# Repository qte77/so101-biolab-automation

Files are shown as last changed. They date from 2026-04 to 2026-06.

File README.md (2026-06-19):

# so101-biolab-automation

> **PROTOTYPE** — This project is in early development. Hardware designs are untested, CAD dimensions are approximate, and USB protocols are being reverse-engineered. Not ready for production use. Contributions and feedback welcome.














Dual-path bio-lab automation: SO-101 arms for complex tasks + XZ gantry for dedicated pipetting. Supports commercial electronic pipettes (AELAB dPette, DLAB dPette+) and Bento Lab PCR.

See [docs/UserStory.md](docs/UserStory.md) for use cases (UC1-5) and acceptance criteria.

**Background:** this is the lab scaffold behind [Building a Trustworthy Agent Loop for a Physical Lab](https://qte77.github.io/open-self-driving-lab-agent-loop/).

## Hardware

**SO-101 path:** Two [SO-101](https://github.com/therobotstudio/so-arm100) follower arms + one leader arm via [LeRobot](https://huggingface.co/docs/lerobot/index). ~$350–$650.

**XZ gantry path:** Dedicated 2-axis pipetting arm (MGN12 rails + NEMA17 steppers). ~$60–$80.

See [docs/hardware/BOM.md](docs/hardware/BOM.md) for full shopping list with links.

## Quick Start

```bash
# Setup (all deps + tools)
make setup_all

# Generate 3D-printed parts (build123d preferred, OpenSCAD fallback)
# STL + STEP + SVG written to hardware/. STEP is the FreeCAD round-trip
# escape hatch when parametric editing is awkward — see docs/hardware/cad-tooling.md.
make render_parts

# Optional: validate printability (CuraEngine / PrusaSlicer)
make setup_slicer
make check_prints

# --- Hardware bringup (one-time) ---

# Install LeRobot deps (PyPI wheels first; falls back to build-from-source if needed)
make setup_hardware

# Identify USB serial ports for each board (unplug one at a time when prompted)
make find_port

# Fix /dev/ttyACM* permissions (one-time; replug boards after)
make install_udev

# Scan servos + patch lerobot for mixed STS3215 firmware
make bringup PORT=/dev/ttyACM1

# Calibrate arms (move each through its full range when prompted)
make calibrate_arms                       # full 3-arm setup (leader + arm_a + arm_b)
# for 2-arm setups (leader + one follower) run only what is connected:
# make calibrate_arm_a calibrate_leader

# Teleoperate (teacher-student)
make start_teleop                         # uses cameras by default
# or headless (no cameras):
# make start_teleop CAMERAS="{}"

# Record pipetting episodes
make record_episodes TASK="pipette row A"

# Train policy
make train_policy

# Run demo
make run_demo
```

## Live Visualization

`make start_teleop` and `make record_episodes` open [Rerun.io](https://rerun.io)
automatically (via `--display_data=true`).

<details>
<summary>Rerun.io live teleop view — click to expand</summary>

Rerun.io live teleop view

- **Top panel** — time-series of commanded `action.*.pos` vs observed `observation.*.pos` for each joint (shoulder_pan, shoulder_lift, elbow_flex, wrist_flex, wrist_roll, gripper)
- **Bottom panel** — observation streams aligned to the action timeline
- **Right panel** — recording metadata (ID, app, timestamps)
- **Left panel** — recording list + blueprint

Useful for verifying leader→follower tracking lag, joint-range coverage during recording, and gripper actuation timing.

</details>

For a separate live 3D arm + camera view (Foxglove), run `make start_foxglove`.

## Architecture

Workspace Layout

See [docs/architecture.md](docs/architecture.md) for full system design, module responsibilities, and data flows.

## Project Structure

- `src/so101/` — core library + CLI entry points (arms, pipette, workflow, safety, ELN)
- `src/dashboard/` — FastAPI remote oversight dashboard
- `src/hardware/` — CAD pipeline (build123d, slicer, renderer)
- `hardware/` — generated STLs, SVGs, 3D scan data
- `configs/` — YAML runtime config (ports, positions, backends)
- `docs/` — design, user stories, demo scenarios, BOM, research, hardware bringup
- `tests/` — unit, integration, property-based tests (80% coverage gate)

See [docs/architecture.md](docs/architecture.md) for module responsibilities and data flows.

## CLI Entry Points

```bash
uv run so101-demo              # run demo pipetting workflows
uv run so101-coord             # send coordinate commands to an arm
uv run so101-scan-servos       # scan serial port for STS3215 servos
uv run so101-patch-lerobot     # patch lerobot for mixed firmware (prototyping)
```

## Documentation

- [Architecture](docs/architecture.md) — system design, module responsibilities, data flows
- [User Stories](docs/UserStory.md) — use case (UC1-5) acceptance criteria
- [Demo Scenarios](docs/demo-scenarios.md) — how to run and verify each use case
- [Hardware BOM](docs/hardware/BOM.md) — shopping list with links ($350-$3000+)
- [Hardware Bringup](docs/hardware/bringup.md) — SO-101 calibration, teleop, firmware patches
- [Research](docs/research.md) — prior art, papers, community designs, insights
- [Roadmap](docs/roadmap.md) — closed-loop printing, tool genesis, VLM/embodied AI vision

## Key Dependencies

- [LeRobot](https://github.com/huggingface/lerobot) — Teleoperation + imitation learning
- [PyLabRobot](https://github.com/PyLabRobot/pylabrobot) — Liquid handling abstractions
- [digital-pipette-v2](https://github.com/ac-rad/digital-pipette-v2) — DIY pipette (alternative backend)
- [build123d](https://github.com/gumyr/build123d) — Primary CAD for 3D-printed parts
- [OpenSCAD](https://openscad.org/) — Fallback CAD for 3D-printed parts
- [CuraEngine](https://github.com/Ultimaker/CuraEngine) — Printability validation (headless, preferred)
- [PrusaSlicer](https://github.com/prusa3d/PrusaSlicer) — Printability validation (fallback)
- FastAPI + WebRTC — Remote dashboard
- OpenCV — Camera pipeline

## Development

For dev setup, testing, and contribution workflow, see [CONTRIBUTING.md](CONTRIBUTING.md) and [AGENTS.md](AGENTS.md).
Run `make help` to list available targets; `make validate` is the canonical quality gate.

## Roadmap

Toward general-purpose voice/agent-to-print. See [docs/roadmap.md](docs/roadmap.md) for full vision (human loop, agent loop, autonomous tool genesis, VLM/embodied AI phases).

## License

Apache-2.0

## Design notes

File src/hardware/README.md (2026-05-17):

---
title: Hardware Parts
purpose: 3D-printable parts index with print settings, assembly, scan references, and source scripts
created: 2026-03-27
updated: 2026-04-11
---

# Hardware Parts

Generated from `parts.json` manifest via `render.py` (build123d preferred, OpenSCAD fallback).

```bash
make setup_cad            # Install build123d (preferred)
make setup_scad           # Install OpenSCAD (fallback)
make render_parts         # Generate STL + SVG from parts.json
make setup_slicer         # Install slicer (optional)
make check_prints         # Check printability
make render_all           # Generate + validate
```

**How it works:** `hardware/parts.json` defines all parts (names, filenames, scripts, build functions). `hardware/render.py` reads the manifest and dispatches to build123d (imports `build_func`, exports STL+SVG) or OpenSCAD (CLI calls with `scad_args`). Adding a part means editing `parts.json` and writing the script.

**Why build123d + slicer?** build123d generates parametric STLs with isometric wireframe SVGs. A slicer (CuraEngine / PrusaSlicer) validates FDM printability (overhangs, unsupported regions, gravity failures) as fast CLI feedback.

**Fallback for hand-edits:** STEP files are exported alongside STL into `../../hardware/step/` so parts can be opened in FreeCAD for WYSIWYG edits (face drag, manual fillet) when parametric Python is awkward. The hand-edited STEP becomes the source of truth for that part — no re-import to build123d. See [../../docs/hardware/cad-tooling.md](../../docs/hardware/cad-tooling.md#hand-edit-round-trip-fallback) for the round-trip and FreeCAD install pointer.

**Status:** EXPERIMENTAL = draft dimensions, untested on hardware.

Generated STL/SVG outputs and reference scans live under the top-level `../../hardware/` directory; only code lives here. See [../../docs/architecture.md](../../docs/architecture.md#hardware-asset-layout) for the authoritative layout description.

## System Overview

Workspace Layout

## Print Settings

| Setting | Default | Exception |
|---|---|---|
| Material | PLA+ | `gripper_tips_tpu.stl` → TPU 95A |
| Nozzle | 0.4mm | — |
| Layer height | 0.2mm | prototype profile → 0.3mm |
| Infill | 15% | functional parts (dpette mounts, tool changer) → 25% |
| Supports | >45° | disabled by default |

Slicer profiles (`slicer/profiles/*.ini`):

- **Generic:** `pla_plus_02mm.ini`, `tpu_95a_02mm.ini` — printer-agnostic
- **Prusa MK4:** `prusa_mk4_pla_02mm.ini` (production), `prusa_mk4_pla_prototype.ini` (fast fit-check), `prusa_mk4_pla_prototype_supports.ini` (with auto-supports), `prusa_mk4_tpu_02mm.ini` (gripper tips on MK4)

Upload to an Original Prusa MK4 via PrusaLink — see [../../docs/hardware/prusa-mk4-ops.md](../../docs/hardware/prusa-mk4-ops.md) for the endpoint reference + curl examples.

## Parts & Assembly

### Tool Changer System

Passive tool changing based on [Berkeley design](https://goldberg.berkeley.edu/pubs/CASE2018-ron-tool-changer-submitted.pdf) (truncated cone + dowel pins + magnets).

| Part | Preview |
|---|---|
| Robot-side cone (female) | tool_cone_robot |
| Tool-side cone — pipette | tool_cone_pipette |
| Tool-side cone — gripper | tool_cone_gripper |
| 3-station dock | tool_dock |

**Assembly order:**

1. **`tool_cone_robot.stl`** — Mount on SO-101 wrist (motor 5 horn, 4× M3 screws). Stays on arm permanently.
2. **`tool_cone_pipette/gripper.stl`** — Attach one to each tool. Glue or screw to tool base.
3. **`tool_dock_3station.stl`** — Fix to workspace. Insert 5mm neodymium magnets in each slot bottom.

**Tool change sequence:** Approach dock → insert tool → retract → move to new slot → push onto cone → retract with new tool.

### Pipette Setup

| Part | Preview |
|---|---|
| Pipette mount | pipette_mount |

1. **`pipette_mount_so101.stl`** — Clamp around dPette barrel. Tighten with 2× M3 screws.
2. Attach `tool_cone_pipette.stl` to mount base (4× M3 or glue).
3. **`tip_rack_holder.stl`** — Place on workspace, insert tip rack. Arm picks tips by pressing pipette into rack.

| Part | Preview |
|---|---|
| Tip rack holder | tip_rack |

### Plate Handling

| Part | Preview |
|---|---|
| 96-well plate holder | plate_holder |

1. **`96well_plate_holder.stl`** — Place at known position. 4 alignment pins locate the plate.

### Gripper Enhancement

| Part | Preview |
|---|---|
| Gripper tips (TPU) | gripper_tips |

1. **`gripper_tips_tpu.stl`** — Press-fit or glue onto SO-101 gripper fingers. Print in TPU 95A.

### dPette+ 8-Channel Mount (replaces SO-101 gripper jaws)

Derived from a 1:1 mm Revopoint 3D scan of the DLAB dPette+ handle (see [Scan Reference Data](#scan-reference-data)). Replaces the stock gripper jaws with a dedicated dPette+ mount:

| Part | Preview |
|---|---|
| Pipette clamp (replaces bottom jaw) | dpette_multi_handle |
| Ejector lever (replaces top jaw) | dpette_ejector_lever |
| Tip ejector station | dpette_tip_release |

**Assembly:**

1. **`dpette_multi_handle.stl`** — Bolts to M5 horn (4× M3 on 20mm BC). Ø32mm split bore clamps the round dPette+ handle; 2× M3 pinch bolts tension the clamp.
2. **`dpette_ejector_lever.stl`** — Bolts to M6 horn (25T spline + 4× M2 on 16mm BC). When M6 rotates (gripper-close motion), the 20mm arm sweeps and pushes down on the ejector hook (~175N from 35 kg-cm stall torque).
3. **`dpette_tip_release.stl`** — L-bracket tip ejector station at a fixed waste position. Robot moves pipette laterally into the horizontal finger to trigger tip ejection; wide waste slot fits both single- and 8-channel tip falls.

### dPette Single-Channel Mount (alternative)

| Part | Preview |
|---|---|
| U-bracket handle | dpette_handle |
| Cam arm | dpette_cam_arm |

1. **`dpette_handle.stl`** — U-bracket (single-sided C-frame): top bar bolts to M5 horn, vertical side holds M6 motor, bottom bar clamps the dPette 7016 single-channel barrel (Ø20mm bore + pinch bolt split).
2. **`dpette_cam_arm.stl`** — Straight radial arm on M6 horn. Sweeps into the ejector hook when M6 rotates.

## Scan Reference Data

Parametric CAD scripts in `cad/dpette/` may be informed by 3D scan data (structured-light scanners like Revopoint) when a physical reference is available. Scans live at the top-level `../../hardware/scans/` directory, **separate** from generated STL/SVG outputs.

Current scans:

| File | Size | Derived parts |
|---|---|---|
| [`../../hardware/scans/dpette/0410_02_mesh.ply`](../../hardware/scans/dpette/0410_02_mesh.ply) | ~2.3 MB | `dpette_multi_handle`, `dpette_ejector_lever` |
| [`../../hardware/scans/dpette/0410_02_mesh.stl`](../../hardware/scans/dpette/0410_02_mesh.stl) | ~4.6 MB | (same; mesh conversion of the PLY above) |

Parts derived from a scan carry an optional `scan_source` field in `parts.json` pointing at the scan file — queryable for tool-genesis workflows and design audits. See [../../hardware/scans/dpette/README.md](../../hardware/scans/dpette/README.md) for provenance and scale.

## Parts Catalog

The machine-readable manifest of all parts (name, STL/SVG outputs, CAD source, build function, status, backend, scan source) is [`parts.json`](parts.json). It is the single source of truth — `render.py` reads it to generate outputs, tests validate it, and this README links to it rather than duplicating it.

Query examples:

```bash
# List all active parts
jq '.[] | select(.status == "active") | .name' src/hardware/parts.json

# Find scan-derived parts
jq '.[] | select(.scan_source) | {name, scan_source}' src/hardware/parts.json
```

## Structural Review Checklist

Before printing, verify each STL:

- [ ] **Mesh integrity** — run `python hardware/slicer/validate.py --all --structural` (checks triangle count, file size)
- [ ] **Connected geometry** — no floating/disconnected features (open in slicer preview, rotate all angles)
- [ ] **Minimum wall thickness** — 0.8mm for 0.4mm nozzle (2 perimeters minimum)
- [ ] **Overhangs** — no unsupported angles > 45° (or add supports)
- [ ] **Bed adhesion** — flat bottom face exists (no point/edge contact)
- [ ] **Fit check** — mating dimensions match hardware (servo horns, magnets, pipette barrel)

## Hardware Needed (Non-Printed)

- 5mm × 3mm neodymium magnets (3 for dock, 4 for cone pairs)
- M3 × 8mm screws (4 for wrist mount, 2 per pipette clamp)
- Glue (CA or epoxy) for cone-to-tool bonding

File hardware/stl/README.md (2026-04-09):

---
title: STL Files Index
purpose: Index of 3D-printable parts with status, print settings, assembly, and source scripts
created: 2026-03-27
updated: 2026-03-30
---

# STL Files

Generated from `../parts.json` manifest via `../render.py` (CadQuery preferred, OpenSCAD fallback).

```bash
make setup_cad            # Install CadQuery (preferred)
make setup_scad           # Install OpenSCAD (fallback)
make render_parts         # Generate STL + SVG from parts.json
make setup_slicer         # Install PrusaSlicer (optional)
make check_prints         # Check printability
make render_all           # Generate + validate
```

**How it works:** `hardware/parts.json` defines all parts (names, filenames, scripts, build functions). `hardware/render.py` reads the manifest and dispatches to CadQuery (imports `build_func`, exports STL+SVG) or OpenSCAD (CLI calls with `scad_args`). Adding a part means editing `parts.json` and writing the script.

**Why CadQuery + slicer?** CadQuery generates parametric STLs with isometric wireframe SVGs. PrusaSlicer validates FDM printability (overhangs, unsupported regions, gravity failures) as fast CLI feedback.

**Status:** EXPERIMENTAL = draft dimensions, untested on hardware.

## System Overview

Workspace Layout

## Print Settings

| Setting | Default | Exception |
|---|---|---|
| Material | PLA+ | `gripper_tips_tpu.stl` → TPU 95A |
| Nozzle | 0.4mm | — |
| Layer height | 0.2mm | — |
| Infill | 15% | — |
| Supports | >45° | — |

## Parts & Assembly

### Tool Changer System

Passive tool changing based on [Berkeley design](https://goldberg.berkeley.edu/pubs/CASE2018-ron-tool-changer-submitted.pdf) (truncated cone + dowel pins + magnets).

| Part | Preview |
|---|---|
| Robot-side cone (female) | tool_cone_robot |
| Tool-side cone — pipette | tool_cone_pipette |
| Tool-side cone — gripper | tool_cone_gripper |
| 3-station dock | tool_dock |

**Assembly order:**

1. **`tool_cone_robot.stl`** — Mount on SO-101 wrist (motor 5 horn, 4× M3 screws). Stays on arm permanently.
2. **`tool_cone_pipette/gripper.stl`** — Attach one to each tool. Glue or screw to tool base.
3. **`tool_dock_3station.stl`** — Fix to workspace. Insert 5mm neodymium magnets in each slot bottom.

**Tool change sequence:** Approach dock → insert tool → retract → move to new slot → push onto cone → retract with new tool.

### Pipette Setup

| Part | Preview |
|---|---|
| Pipette mount | pipette_mount |

1. **`pipette_mount_so101.stl`** — Clamp around [digital-pipette-v2](https://github.com/ac-rad/digital-pipette-v2) barrel. Tighten with 2× M3 screws.
2. Attach `tool_cone_pipette.stl` to mount base (4× M3 or glue).
3. **`tip_rack_holder.stl`** — Place on workspace, insert tip rack. Arm picks tips by pressing pipette into rack.

| Part | Preview |
|---|---|
| Tip rack holder | tip_rack |

### Plate Handling

| Part | Preview |
|---|---|
| 96-well plate holder | plate_holder |

1. **`96well_plate_holder.stl`** — Place at known position. 4 alignment pins locate the plate.

### Gripper Enhancement

| Part | Preview |
|---|---|
| Gripper tips (TPU) | gripper_tips |

1. **`gripper_tips_tpu.stl`** — Press-fit or glue onto SO-101 gripper fingers. Print in TPU 95A.

## Parts Table

| STL File | SVG | Source | Description |
|---|-----|---|---|
| `tool_cone_robot.stl` | [svg](../svg/tool_cone_robot.svg) | `tool_changer.py` | Female cone — mounts on SO-101 wrist |
| `tool_cone_pipette.stl` | [svg](../svg/tool_cone_pipette.svg) | `tool_changer.py` | Male cone — pipette tool base |
| `tool_cone_gripper.stl` | [svg](../svg/tool_cone_gripper.svg) | `tool_changer.py` | Male cone — gripper tool base |
| `tool_dock_3station.stl` | [svg](../svg/tool_dock_3station.svg) | `so101/tool_dock.py` | 3-slot parking rack with magnet pockets |
| `pipette_mount_so101.stl` | [svg](../svg/pipette_mount_so101.svg) | `so101/pipette_mount.py` | dPette barrel clamp for SO-101 wrist |
| `96well_plate_holder.stl` | [svg](../svg/96well_plate_holder.svg) | `labware/plate_holder.py` | SBS plate holder with alignment pins |
| `tip_rack_holder.stl` | [svg](../svg/tip_rack_holder.svg) | `labware/tip_rack_holder.py` | Tip rack tray |
| `gripper_tips_tpu.stl` | [svg](../svg/gripper_tips_tpu.svg) | `so101/gripper_tips.py` | Compliant fingertips (TPU 95A) |
| `dpette_single_cradle.stl` | [svg](../svg/dpette_single_cradle.svg) | `dpette/dpette_cradle.py` | Rest cradle for dPette 7016 |
| `dpette_multi_cradle.stl` | [svg](../svg/dpette_multi_cradle.svg) | `dpette/dpette_cradle.py` | Rest cradle for dPette+ 8-channel |
| `tip_ejection_bar.stl` | [svg](../svg/tip_ejection_bar.svg) | `dpette/tip_ejection_bar.py` | Tip ejection post (top-button) |

## Structural Review Checklist

Before printing, verify each STL:

- [ ] **Mesh integrity** — run `python hardware/slicer/validate.py --all --structural` (checks triangle count, file size)
- [ ] **Connected geometry** — no floating/disconnected features (open in slicer preview, rotate all angles)
- [ ] **Minimum wall thickness** — 0.8mm for 0.4mm nozzle (2 perimeters minimum)
- [ ] **Overhangs** — no unsupported angles > 45° (or add supports)
- [ ] **Bed adhesion** — flat bottom face exists (no point/edge contact)
- [ ] **Fit check** — mating dimensions match hardware (servo horns, magnets, pipette barrel)

## Hardware Needed (Non-Printed)

- 5mm × 3mm neodymium magnets (3 for dock, 4 for cone pairs)
- M3 × 8mm screws (4 for wrist mount, 2 per pipette clamp)
- Glue (CA or epoxy) for cone-to-tool bonding

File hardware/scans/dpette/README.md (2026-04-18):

# dPette+ 3D Scan Reference Data

Source mesh used to redesign the dPette+ 8-channel mount geometry
(`src/hardware/cad/dpette/dpette_multi_handle.py` + `dpette_ejector_lever.py`).

## Files

| File | Size | Format | Source |
|---|---|---|---|
| `0410_02_mesh.ply` | ~2.3 MB | Stanford PLY (binary) | Revopoint 3D scan, 2026-04-10 |
| `0410_02_mesh.stl` | ~4.6 MB | Binary STL (derived) | PLY → STL conversion |

## Scale & Coordinates

- **1:1 mm** — no scaling applied
- Origin and axes match Revopoint scanner output (no re-orientation)

## Intended use

Reference geometry for parametric rebuilds of dPette+-specific parts.
Not meant to be 3D printed directly — use the parametric build123d
scripts in `src/hardware/cad/dpette/` for printable parts.

## Provenance

Captured by Antonio Lamb (@antomicblitz) and incorporated via PR #48.
Preserved here as-is under the project's Apache-2.0 license (same as
the rest of the repo).

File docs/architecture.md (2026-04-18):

---
title: Architecture
purpose: System design, module responsibilities, data flows, stub mode, design decisions
authority: System design (AUTHORITY)
created: 2026-03-27
updated: 2026-04-10
---

# Architecture

## System Overview

```text
┌──────────────────────────────────────────────────────┐
│                  Remote Dashboard                     │
│  FastAPI + WebSocket commands + REST /api/status      │
│  src/dashboard/server.py                              │
└──────────────────┬───────────────────────────────────┘
                   │ WebSocket: e_stop, heartbeat,
                   │ target_well, run_workflow
┌──────────────────▼───────────────────────────────────┐
│               Workflow Orchestration                  │
│  src/so101/workflow.py                               │
│  Composes modules into use cases (UC1-4)              │
│  Loads PlateLayout from configs/plate_layout.yaml     │
├──────────┬──────────┬──────────┬─────────────────────┤
│  Arms    │ Pipette  │  Tool    │  Safety             │
│  Control │ Control  │  Changer │  Monitor            │
│ arms.py  │pipette.py│tool_ch.. │ safety.py           │
└────┬─────┴────┬─────┴────┬─────┴─────────────────────┘
     │          │          │
     │     ┌────▼────┐     │
     │     │ Plate   │     │
     │     │ Geometry │     │
     │     │plate.py │     │
     │     └─────────┘     │
     │                     │
┌────▼─────────────────────▼───┐
│  LeRobot / Serial / Hardware │
│  (stub mode when unavailable)│
└──────────────────────────────┘
```

## Module Responsibilities

| Module | File | Responsibility | Dependencies |
|---|---|---|---|
| **Workflow** | `src/so101/workflow.py` | Orchestrates use cases (UC1-5) by composing other modules | arms, pipette, plate, tool_changer, xz_gantry |
| **Arms** | `src/so101/arms.py` | Dual SO-101 arm control via LeRobot. Config-driven named positions, sequences, teleoperation skeleton. Stub mode when lerobot absent. | plate (for send_to_well) |
| **Pipette** | `src/so101/pipette.py` | Multi-backend pipette control (`PipetteProtocol`). Backends: `DigitalPipette` (DIY/Arduino), `ElectronicPipette` (AELAB/DLAB). Stub mode when pyserial absent. | None |
| **XZ Gantry** | `src/so101/xz_gantry.py` | Dedicated 2-axis pipetting arm (simpler than SO-101). Stub mode when serial absent. | None |
| **Bento Lab** | `src/so101/bento_lab.py` | Portable PCR thermocycler control (lid, programs, status). Stub mode when serial absent. | None |
| **Plate** | `src/so101/plate.py` | Pure SBS 96-well coordinate math. No hardware deps. | None |
| **Tool Changer** | `src/so101/tool_changer.py` | 3-tool magnetic dock: pipette, gripper, fridge hook. | arms (for send_action) |
| **Camera** | `src/so101/camera.py` | Multi-camera capture via OpenCV. Stub mode when cv2 absent. | None |
| **Safety** | `src/so101/safety.py` | Watchdog, e-stop, joint limits. Pure Python. | None |
| **Dashboard** | `src/dashboard/server.py` | FastAPI server with WebSocket commands and REST status. | All biolab modules |

## Data Flow: Pipetting a Well

```text
User/Dashboard → workflow.pipette_well()
  1. arm.execute_sequence("arm_a", ["trough_approach", "trough_lower"])  → arms.py → LeRobot
  2. pipette.aspirate(50.0)                → pipette.py → Arduino serial (stub: track fill)
  3. arm.execute_sequence("arm_a", ["well_approach", "well_lower"])      → arms.py → LeRobot
  4. pipette.dispense(50.0)                → pipette.py → Arduino serial (stub: track fill)
```

## Data Flow: Tool Change

```text
workflow.uc2_fridge_open_grab_move()
  1. changer.change_tool(FRIDGE_HOOK)      → tool_changer.py → arms.send_action (dock sequence)
  2. arm.send_action(FRIDGE_APPROACH)       → arms.py → LeRobot
  3. arm.send_action(FRIDGE_HOOK_ENGAGED)   → arms.py → LeRobot
  4. changer.change_tool(GRIPPER)           → tool_changer.py → arms.send_action (dock sequence)
  5. arm.send_action(FRIDGE_GRAB)           → arms.py → LeRobot
```

## Configuration Files

| File | Loaded By | Content |
|---|---|---|
| `configs/arms.yaml` | `DualArmConfig.from_yaml()` | Arm ports, cameras, named positions (park, home, well_approach, etc.) |
| `configs/plate_layout.yaml` | `PlateLayout.from_yaml()` | Workspace origin, Z heights, trough position |
| `configs/tool_dock.yaml` | `ToolDockConfig.from_yaml()` | Joint arrays for 3 dock stations |
| `configs/pipette.yaml` | `_create_pipette()` | Backend selection (digital/electronic) + per-backend settings |
| `configs/xz_gantry.yaml` | `XZGantryConfig.from_yaml()` | Named positions, serial port, controller type |
| `configs/bento_lab.yaml` | `BentoLabConfig` | Serial port, PCR program definitions |

## Stub Mode

Every hardware-dependent module gracefully degrades when its dependency is unavailable:

| Module | Trigger | Behavior |
|---|---|---|
| arms.py | `ImportError` on `lerobot` | `send_action` logs and returns; `get_observation` returns `{"stub": True}` |
| pipette.py | `ImportError` on `serial` | Fill state tracked in memory; serial commands are no-ops |
| xz_gantry.py | `ImportError` on `serial` | Position tracked in memory; serial commands are no-ops |
| bento_lab.py | `ImportError` on `serial` | State (lid, program) tracked in memory; serial commands are no-ops |
| camera.py | `ImportError` on `cv2` | `start()` returns; `get_frames()` returns `{}` |

This allows the full workflow to run end-to-end without any hardware attached. Run `make run_tests` to verify.

## Key Design Decisions

- **No IK**: `send_to_well()` uses config `well_approach` position; real inverse kinematics deferred to MVP (requires calibrated hardware). Named positions in `configs/arms.yaml` are placeholders.
- **PlateLayout in workflow.py**: Separates pure SBS math (plate.py) from hardware workspace config (workflow.py). Single responsibility.
- **No fridge module**: Fridge joint arrays are constants in workflow.py. YAGNI until hardware exists.
- **Dashboard runs workflow in thread**: `run_workflow` WebSocket command spawns `uc4_demo_all` in a daemon thread to avoid blocking the event loop.

## Hardware Asset Layout

Build-time assets (generated STL/SVG, reference scans) are kept separate from code:

- **Code** — `src/hardware/` (authoritative): `cad/` (build123d parametric scripts, primary), `scad/` (OpenSCAD fallback), `slicer/` (profile validation), `parts.json` (manifest), `render.py` (dispatcher).
- **Assets** — top-level `hardware/`: `stl/` (generated printable meshes), `svg/` (generated isometric wireframes), `scans/` (reference 3D scans from Revopoint / structured light, used as design inputs).

Parts in `src/hardware/parts.json` may carry an optional `scan_source` field pointing at a file under `hardware/scans/` when their geometry is derived from a physical scan rather than being purely parametric. Example: `dpette_multi_handle` (Ø32mm split-bore clamp) was designed from a 1:1 mm Revopoint scan of the DLAB dPette+ handle.

See [src/hardware/README.md](../src/hardware/README.md) for the full parts table, print settings, assembly notes, and scan provenance.

## Prior Art & Vision

- [docs/research.md](research.md) — prior art, papers, community designs, insights informing these decisions
- [docs/roadmap.md](roadmap.md) — forward-looking direction (closed-loop printing, tool genesis, VLM/embodied AI phases)

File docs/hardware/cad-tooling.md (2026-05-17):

---
title: CAD, Slicer & Simulation Tooling
purpose: CAD library decisions, slicer CLI comparison, SO-101 simulation stacks, STL build status
authority: Research (INFORMATIONAL — not requirements)
created: 2026-03-27
updated: 2026-04-12
---

# CAD, Slicer & Simulation Tooling

## CAD Library Comparison

**Problem:** CadQuery generates geometrically correct STLs but has no FDM awareness. Vertical empty rows, unsupported overhangs, and gravity failures are invisible until a print fails.

| Feature | CadQuery | Build123d | OpenSCAD | JSCAD | FreeCAD | Blender (bpy) |
|---|---|---|---|---|---|---|
| Language | Python | Python | Own syntax | JavaScript | GUI + Python | Python |
| Paradigm | Parametric, BREP | Parametric, BREP | CSG only | CSG only | Full CAD | Mesh-based |
| Output | STEP, STL, DXF | STEP, STL | STL only | STL, OBJ | STEP, STL, many | STL, OBJ, many |
| Curve quality | Excellent | Excellent | Faceted | Faceted | Excellent | Mesh |
| For 3D printing | Great | Great | Common | OK | Great | Needs cleanup |
| For mechanical parts | Best in class | Very good | Limited | Limited | Best in class | Not ideal |
| Learning curve | Medium | Low-Medium | Low | Low | High | High |
| Browser-based | No | No | No | Yes | No | No |
| Open source | Yes | Yes | Yes | Yes | Yes | Yes |
| Python 3.13+ support | No (VTK blocked) | Yes | N/A | N/A | Yes | Yes |

**Decision (2026-04):** Migrating from CadQuery to **build123d** — same BREP kernel (OCP), lower learning curve, algebraic operators (`+`/`-` instead of `.union()`/`.cut()`), and builds on Python 3.13 where CadQuery's VTK dependency does not.

## OpenSCAD CLI

Mature, stable parametric CAD. `.scad` -> STL/SVG/DXF/PNG via CLI.

```bash
openscad -o out.stl input.scad                    # export STL
openscad -o out.svg --projection=ortho input.scad  # export SVG
openscad -D 'length=100' -o out.stl input.scad     # parametric override
openscad -p params.json -P set_name -o out.stl input.scad  # parameter file
```

- Install: `apt install openscad`, snap, flatpak, or AppImage
- CSG maps 1:1 from CadQuery: `box`->`cube`, `cylinder`->`cylinder`, `cut`->`difference()`, `revolve`->`rotate_extrude()`
- No printability validation (must pair with slicer)

## Slicer CLI Comparison

| Tool | CLI Maturity | Headless Linux | Overhang Detection | Notes |
|---|---|---|---|---|
| **PrusaSlicer** | Mature | Yes | Yes | `prusa-slicer --export-gcode model.stl --load config.ini`. Most stable. [Wiki](https://github.com/prusa3d/PrusaSlicer/wiki/Command-Line-Interface) |
| **Bambu Studio** | Modern | Yes (Docker avail) | Yes | `--slice`, `--orient`, `--arrange`, JSON config. Best error codes. [Wiki](https://github.com/bambulab/BambuStudio/wiki/Command-Line-Usage) |
| **SuperSlicer** | Mature | Yes | Enhanced | PrusaSlicer fork with better overhang detection. [Docs](https://docs.superslicer.org/advanced-usage-guides/cmd-line-guide/) |
| **CuraEngine** | Stable | Yes | Limited | Pure engine, no GUI deps. JSON settings. [GitHub](https://github.com/Ultimaker/CuraEngine) |
| **OrcaSlicer** | **Broken** | **No** (GTK3 crashes) | Yes (when it works) | CLI shares GUI code, segfaults headless. [#2714](https://github.com/OrcaSlicer/OrcaSlicer/issues/2714), [#12277](https://github.com/OrcaSlicer/OrcaSlicer/issues/12277) |

**OrcaSlicer CLI root cause:** wxWidgets 3.1.7 (GTK3 backend) initializes display context even in CLI mode. Stack: `libslic3r` (core, decoupled) -> `libslic3r_gui` (wxWidgets) -> single binary. Fork lineage: Slic3r -> PrusaSlicer -> Bambu Studio -> OrcaSlicer (all share `libslic3r` core).

**Recommendation:** PrusaSlicer CLI for validation (stable, proven). Keep slicer-agnostic so Bambu Studio or SuperSlicer can substitute.

## SO-101 Simulation & Digital Twin

**Goal:** Catch hardware problems in software. Shift-left testing for robotics.

**Official SO-101 sim models:** URDF + MJCF at [TheRobotStudio/SO-ARM100/Simulation/SO101](https://github.com/TheRobotStudio/SO-ARM100/tree/main/Simulation/SO101). Includes `so101_new_calib.urdf`, `so101_new_calib.xml` (MuJoCo), `scene.xml`, joint properties, mesh assets. Generated via onshape-to-robot.

### Simulation Stacks

| Stack | Physics | GPU | SO-101 Tasks | Headless CI | Use for |
|---|---|-----|---|---|---|
| [MuJoCo](https://mujoco.readthedocs.io/) direct | MuJoCo 3.0+ | No | Via URDF/MJCF | Yes (`MUJOCO_GL=osmesa`) | CI tests, lightweight sim, control dev |
| [LeIsaac](https://github.com/LightwheelAI/leisaac) | Isaac Lab | Yes | `PickOrange`, `LiftCube`, `CleanToyTable`, `FoldCloth-BiArm` | Cloud (NVIDIA Brev) | Teleoperation, data collection, policy training |
| [ManiSkill](https://github.com/haosulab/ManiSkill) | SAPIEN | Yes | Via custom robot loading | Limited | RL training, GPU-parallelized (200k+ FPS) |
| [gym_hil](https://github.com/huggingface/gym-hil) | MuJoCo | No | Panda only (extensible) | Yes | Human-in-the-loop RL |

**LeIsaac details:**

- Official LeRobot EnvHub integration by [LightwheelAI](https://lightwheelai.github.io/leisaac/)
- SO101 follower + leader teleoperation in sim
- HDF5 -> LeRobot dataset conversion built-in
- Cloud sim: no local GPU required via NVIDIA Brev
- Usage: `make_env("LightwheelAI/leisaac_env:envs/so101_pick_orange.py", n_envs=1, trust_remote_code=True)`

**MuJoCo in CI (headless GitHub Actions):**

- Set `MUJOCO_GL=osmesa` for software rendering (no GPU, no X11)
- Install: `sudo apt-get install libosmesa6-dev`
- Proven pattern: MuJoCo official CI, openai/mujoco-py, community SO-100 sim

**OpenSCAD STL -> MuJoCo collision mesh:**

- Export binary STL from OpenSCAD -> reference in MJCF `<mesh>` tag
- MuJoCo auto-converts to convex hull for collision (sufficient for simple parts)
- Works for plate holders, tool changer cones, dock — may need simplification for complex geometry

### Sim-to-Real

- [lerobot-sim2real](https://github.com/StoneT2000/lerobot-sim2real): train in ManiSkill, deploy zero-shot to real SO-101
- GR00T-N1.5 policy fine-tuning on SO-101 via LeIsaac sim data
- Domain randomization (colors, textures, dynamics) for robust transfer
- Community SO-100 MuJoCo: [lachlanhurst/so100-mujoco-sim](https://github.com/lachlanhurst/so100-mujoco-sim) with Qt GUI + LeRobot sync

### Digital Twin for 3D Print Inspection

- Real-time layer-by-layer CNN inspection for over/under-extrusion ([MDPI 2025](https://www.mdpi.com/2075-1702/13/6/448))
- Zero-shot multi-criteria inspection via digital twin ([arXiv 2511.23214](https://arxiv.org/abs/2511.23214))
- 3D Gaussian Splatting for photorealistic rendering of printed parts
- [Systematic review: Digital Twins in 3D Printing](https://arxiv.org/html/2409.00877v1)

**Recommendation:**

1. **CI testing now:** MuJoCo + OSMesa (no GPU, headless, free)
2. **Policy training later:** LeIsaac when GPU available (or NVIDIA Brev cloud)
3. **Print inspection future:** Prototype with real camera + simulated geometry comparison

## XLeRobot Reference

[XLeRobot](https://github.com/Vector-Wangel/XLeRobot) — dual SO-101 mobile platform ($660, <4h assembly).

- Uses STEP + 3MF workflow (no code-generated CAD)
- Distributes STEP files for modification, STL/3MF for printing
- Addresses gravity/support via documentation + manual slicer orientation
- Z-axis scaling in slicer for fit adjustments (not in CAD)
- No automated printability checking
- Proves slicer-based workflow is viable for SO-101 ecosystem

## Hand-edit Round-trip (Fallback)

build123d is the happy path. When a part needs WYSIWYG edits (face drag, manual
fillet, scan-trace cleanup) that are awkward to express parametrically, drop
into FreeCAD via STEP:

```text
build123d (.py) → STEP → FreeCAD GUI (edit) → STEP → PrusaSlicer CLI → gcode
```

- STEP files ship next to STL/SVG at `hardware/step/<subdir>/` (written by
  `src/hardware/cad/util/export.py`, committed for review).
- FreeCAD install is a dev-machine concern only — not a CI dep. STEP export
  itself is pure Python (build123d/OCP) and runs headless. Install via
  `make setup_freecad` (Flatpak on Linux, Homebrew cask on macOS); manual
  paths and AppImage are listed in the
  [FreeCAD install docs](https://wiki.freecad.org/Download).
- Hand-edits are **leaf nodes**: a hand-edited `.step` is the source of truth
  for that part going forward. No automated re-import to build123d.
- Slice a hand-edited STEP the same way as a generated STL — load it in
  PrusaSlicer GUI or convert to STL first (FreeCAD: `File → Export → .stl`).

## Validation Pipeline (Planned)

```text
OpenSCAD (.scad) --> STL --> PrusaSlicer CLI --> printability report
```

- OpenSCAD: parametric generator (reliable CLI, SVG via projection) — archived under `src/hardware/scad/`
- PrusaSlicer / CuraEngine: printability validator (optional, graceful fallback if unavailable)
- build123d: primary CAD backend in `src/hardware/cad/` (migrated from CadQuery 2026-04; scan-informed CAD delivered 2026-04-11)
- **PrusaLink API**: first concrete printer-API integration — see [`prusa-mk4-ops.md`](prusa-mk4-ops.md) for MK4 endpoint reference and curl examples

## STL Files Status

See [`src/hardware/parts.json`](../../src/hardware/parts.json) for the machine-readable manifest and [`src/hardware/README.md`](../../src/hardware/README.md) for the assembly guide. All parts are rendered via `make render_parts` (build123d primary, OpenSCAD fallback) into top-level `hardware/stl/`.

As of 2026-04-11:

- **11 legacy parts** (tool changer system, pipette mount, plate holder, tip rack holder, gripper tips, dPette cradles, tip ejection bar) — all ported to build123d in Phase 2, rendered at `hardware/stl/{so101,labware,dpette}/`
- **5 new dPette+ parts** from Antonio's PR #48 (ported to build123d):
  - `dpette_handle` / `dpette_cam_arm` — U-bracket single-channel mount (M5 horn -> dPette 7016 barrel)
  - `dpette_tip_release` — L-bracket tip ejector station, universal single/multi-channel
  - `dpette_multi_handle` / `dpette_ejector_lever` — 32mm split-bore 8-channel clamp replacing SO-101 gripper jaws, **derived from a 1:1 mm Revopoint scan** (see `hardware/scans/dpette/`)

**Print settings:** PLA+ default, 0.4mm nozzle, 0.2mm layer, 15% infill (25% for functional mounts). TPU 95A for gripper tips only. Prusa MK4 profiles available in `src/hardware/slicer/profiles/prusa_mk4_*.ini`.

**Design philosophy:** STL files are generated programmatically from build123d parametric scripts — reproducible, parametric, version-controlled. OpenSCAD scripts under `src/hardware/scad/` are archived as a fallback. Scan-derived geometry (Revopoint or similar) is captured at 1:1 mm in `hardware/scans/`; the parts.json `scan_source` field provides queryable provenance.

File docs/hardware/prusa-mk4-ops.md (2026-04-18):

# PrusaLink API Reference — Prusa MK4

Printer: **Original Prusa MK4** (PrusaLink 2.1.2, API 2.0.0)
Host: `192.168.1.86` / `prusa-mk4.local`
Serial: `10589-3742441633503380`
Auth: HTTP Digest (`maker` / see `~/prusa_mk4_pw`)

## Endpoints

### System

| Method | Endpoint | Description |
|---|---|---|
| GET | `/api/version` | API/firmware version, nozzle diameter, capabilities |
| GET | `/api/v1/info` | Printer serial, nozzle, MMU status, min extrusion temp |

### Printer Status

| Method | Endpoint | Description |
|---|---|---|
| GET | `/api/v1/status` | Live printer state, bed/nozzle temps, axis positions, fan speeds, job progress |

### Job Control

| Method | Endpoint | Description |
|---|---|---|
| GET | `/api/v1/job` | Current job details (file, progress %, time elapsed) |
| DELETE | `/api/v1/job/{id}` | Cancel/stop a running print |
| PUT | `/api/v1/job/{id}/pause` | Pause a running print |
| PUT | `/api/v1/job/{id}/resume` | Resume a paused print |

### Storage

| Method | Endpoint | Description |
|---|---|---|
| GET | `/api/v1/storage` | List storage devices (USB only on this printer) |

### File Management

| Method | Endpoint | Description |
|---|---|---|
| GET | `/api/v1/files/usb` | List all files/folders on USB |
| PUT | `/api/v1/files/usb/{filename}` | Upload gcode file (binary body) |
| DELETE | `/api/v1/files/usb/{filename}` | Delete a file |
| POST | `/api/v1/files/usb/{filename}` | Start print (`{"command":"start"}`) |

### Transfer

| Method | Endpoint | Description |
|---|---|---|
| GET | `/api/v1/transfer` | File transfer status |
| DELETE | `/api/v1/transfer/{id}` | Cancel active transfer |

### Cameras

| Method | Endpoint | Description |
|---|---|---|
| GET | `/api/v1/cameras` | List active cameras |
| GET | `/api/v1/cameras/snap` | Capture from default camera |
| GET | `/api/v1/cameras/{id}/snap` | Capture from specific camera |
| POST | `/api/v1/cameras/{id}/snap` | Take manual snapshot |
| POST | `/api/v1/cameras/{id}` | Setup or fix a camera |
| DELETE | `/api/v1/cameras/{id}` | Delete a camera |
| PATCH | `/api/v1/cameras/{id}/config` | Update camera settings |

## Headers

| Header | Value | Description |
|---|---|---|
| `Content-Type` | `application/octet-stream` | Required for PUT upload |
| `Print-After-Upload` | `?1` or `?0` | Auto-start print after upload |

## Examples

```bash
# Check printer status
curl -s --digest -u "maker:$PRUSA_PW" http://192.168.1.86/api/v1/status

# Upload gcode
curl -s --digest -u "maker:$PRUSA_PW" \
  -X PUT -H "Content-Type: application/octet-stream" \
  --data-binary @mypart.gcode \
  http://192.168.1.86/api/v1/files/usb/mypart.gcode

# Upload and print immediately
curl -s --digest -u "maker:$PRUSA_PW" \
  -X PUT -H "Content-Type: application/octet-stream" \
  -H "Print-After-Upload: ?1" \
  --data-binary @mypart.gcode \
  http://192.168.1.86/api/v1/files/usb/mypart.gcode

# Start a print
curl -s --digest -u "maker:$PRUSA_PW" \
  -X POST -H "Content-Type: application/json" \
  -d '{"command":"start"}' \
  http://192.168.1.86/api/v1/files/usb/MYPART~1.GCO

# Cancel current print
curl -s --digest -u "maker:$PRUSA_PW" \
  -X DELETE http://192.168.1.86/api/v1/job/294

# Delete a file from USB
curl -s --digest -u "maker:$PRUSA_PW" \
  -X DELETE http://192.168.1.86/api/v1/files/usb/OLDFILE~1.GCO

# List USB files
curl -s --digest -u "maker:$PRUSA_PW" http://192.168.1.86/api/v1/files/usb
```

## CAD-to-Print Pipeline

```text
build123d (.py) → STL → PrusaSlicer → .gcode → PrusaLink PUT → print
```

Parts live in `hardware/stl/dpette/` and `hardware/stl/so101/` (generated assets). CAD sources live in `src/hardware/cad/` (build123d is the primary backend).

Key printable parts:

| STL | Material | Notes |
|-----|---|---|
| `dpette_handle.stl` | PLA+ | U-bracket mount, single-channel |
| `dpette_multi_handle.stl` | PLA+ | U-bracket mount, 8-channel (Ø32mm split-bore clamp for DLAB dPette+) |
| `dpette_ejector_lever.stl` | PLA+ | Tip ejection lever for 8-channel pipette |

Slicer profile: `src/hardware/slicer/profiles/prusa_mk4_pla_02mm.ini`
Generate gcode: `prusa-slicer --load src/hardware/slicer/profiles/prusa_mk4_pla_02mm.ini --export-gcode -o output.gcode hardware/stl/dpette/<part>.stl`

## Notes

- Only **USB** storage is writable; `local` returns 403
- Uploaded `.gcode` files appear with 8.3 short names (e.g., `DPETTE~1.GCO`)
- The `display_name` field in responses shows the original filename
- Nozzle: 0.40mm, no MMU, min extrusion temp: 170C
- Capabilities: `upload-by-put: true`

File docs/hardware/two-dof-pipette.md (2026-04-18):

---
title: 2-DOF Pipette Mode (SO-101 Variant)
purpose: Use SO-101 as a 2-axis positioner with fixed pipette mount — shoulder_pan + shoulder_lift only
authority: Variant configuration (INFORMATIONAL — references bringup.md and architecture.md)
created: 2026-04-14
---

# 2-DOF Pipette Mode

Alternate SO-101 configuration: **use only shoulder_pan + shoulder_lift** (joints
1 and 2) as a 2-axis positioner. A fixed pipette mount replaces the lower arm
(elbow, wrist, gripper) for simple pipetting workflows.

For standard 6-DOF bringup, see [bringup.md](bringup.md).
For roadmap context, see [../roadmap.md](../roadmap.md).

## Rationale

- Pipetting often only needs **reach + height** — elbow/wrist articulation is
  unnecessary overhead
- Electronic pipette (USB-controlled) handles aspirate/dispense — no servo needed
  for plunger
- Simpler kinematics, smaller workspace, cheaper spares (fewer moving servos)

## Mechanical

- Pipette mount attaches **to the upper arm** (post-shoulder, pre-elbow region)
- Lower arm (servos 3-6) either:
  - **Removed entirely** — need mechanical plug/cap at upper arm end
  - **Left attached, parked** — servos 3-6 hold a fixed pose; simplest, no
    structural changes
- Electronic pipette (e.g. AELAB dPette 7016, DLAB dPette+) plugged via USB
  directly to the host PC — plunger actuation is independent of SO-101 servos

## LeRobot Integration Options

LeRobot's `SOFollower` hardcodes all 6 servos in `__init__` (see
`.venv/lib/python3.12/site-packages/lerobot/robots/so_follower/so_follower.py:54-61`).
Three ways to use it with fewer motors:

### Option A — Skip lerobot, use scservo_sdk directly (recommended)

Minimal 2-servo controller in `src/so101/two_dof_arm.py` talking directly to
`scservo_sdk.PacketHandler`. No patches needed. No 6-DOF infrastructure.

**Pros:** Clean, minimal, no lerobot coupling.
**Cons:** No free policy training / episode recording / teleop (but for fixed
pipette mode, leader-follower teleop doesn't make much sense anyway).

### Option B — Patch `SOFollower` to use only 2 motors

Add a 4th patch to `src/so101/cli/patch_lerobot.py` that rewrites the motor
dict in `SOFollower.__init__` to only `shoulder_pan` and `shoulder_lift`.

**Pros:** Reuse `lerobot-calibrate`, `lerobot-teleoperate`, etc.
**Cons:** Another installed-package patch to maintain. Calibration files from
this mode won't match 6-DOF files.

### Option C — Subclass in our project

Create `src/so101/two_dof_follower.py` that inherits `SOFollower` and overrides
`__init__` with only the 2 motors. Used via our `DualArmController`, not
lerobot CLI.

**Pros:** No upstream patch; clean separation.
**Cons:** Loses lerobot CLI compatibility (can't use `lerobot-teleoperate`
unless we also register a custom robot type with draccus).

## Plunger Actuation

Electronic pipette USB protocols are backend-specific. See `src/so101/pipette.py`
(skeleton) and the BOM for recommended models (AELAB dPette 7016 single-channel,
DLAB dPette+ 8-channel).

## Recalibration

If swapping from gripper to pipette mount changes joint 1-2 offsets (e.g. the
mount shifts center of mass or adds a lever arm that affects homing), rerun
`lerobot-calibrate` for just those joints (requires Option B or C).

Otherwise, standard 6-DOF calibration is fine — joints 3-6 hold their park pose
and are never commanded to move.

## Known Constraints

- **Workspace** — limited to a cylindrical sector defined by arm length,
  shoulder_pan range, and shoulder_lift range (no Z-reach beyond the fixed arm
  length)
- **Tip pickup** — pipette must press into tip rack by moving the whole arm
  (shoulder_lift down); no independent Z-axis
- **Tip ejection** — electronic pipette's built-in ejector button (manual or
  USB command) since there's no gripper servo to drive the ejector lever

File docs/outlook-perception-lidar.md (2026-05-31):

---
title: "Outlook: Perception — LIDAR, depth sensing, and digital twin"
purpose: Landscape survey of 3D sensing options (LIDAR, depth, photogrammetry) and BIM/digital-twin integration for spatial awareness in the agentic biolab.
authority: Research (INFORMATIONAL — not requirements)
created: 2026-05-31
updated: 2026-05-31
---

# Outlook: Perception — LIDAR, depth sensing, and digital twin

## Concept

The agentic system today operates on **pre-taught named positions only**. It
has no sense of whether the deck still matches what was taught, whether a
plate has shifted, whether an operator's hand is in the swept volume, or — at
the larger scale — where it is in the lab. This document surveys the sensor
and software stacks that could close that gap, separates them by spatial
scale, and records relevance / feasibility for this repo.

Two distinct scales are in scope. They do **not** share a sensor class or a
software stack and should be treated as independent tracks:

| Track | Scale | Use case | Sensor class | Map representation |
|---|---|---|---|---|
| (a) Workcell | ≤ 500 mm | Pre-move clearance, deck-state check, operator-hand safety | Short-range depth (structured light / ToF) + fiducials | Small URDF / USD scene with bounding boxes |
| (b) Lab-room | 3-15 m | Mobile-base navigation, multi-station routing, layout digital twin | 360° LIDAR + IMU (SLAM) | Georeferenced point cloud → USD / IFC |

Tracking issues: **#perc-a** (workcell), **#perc-b** (lab-room).

## Reference projects analyzed

### OpenScan — <https://openscan.eu>

Open-source **photogrammetry** scanner: turntable + camera + Raspberry Pi.
Generates dense meshes of small objects (cm scale).

- **Relevance:** Low for surroundings awareness. OpenScan is object-scale, fully
  offline, takes minutes per scan. Useful only as a tool to digitize one-off
  labware (custom cradles, 3D-printed adapters) into the URDF/USD scene used by
  track (a).
- **Feasibility:** Trivial — it is a self-contained appliance, not an integration.
  Output is STL/OBJ that feeds the existing `tools/cad/` pipeline.

### `github.com/topics/3d-lidar` — survey topic

Aggregator for LIDAR-related repos. Content is dominated by autonomous-driving
stacks (Autoware, Apollo, KITTI tooling) and outdoor mapping.

- **Relevance:** Low directly, but the topic surfaces the indoor SLAM subset
  (FAST-LIO, Point-LIO, GLIM, HBA, MAD-ICP) that is the actual reference for
  track (b).
- **Feasibility:** Not a project — a discovery surface. Use it to pick the SLAM
  backend once a LIDAR is on a mobile base.

### MANDEYE — <https://github.com/januszbedkowski/mandeye_controller>

Handheld Livox Mid-360 + IMU logger, MIT-licensed. Companion project
**HDMapping** (`MapsHD/HDMapping`) processes the logs offline into
georeferenced point clouds.

- **Relevance:** High for track (b). It is the closest published reference to
  what a single lab-mapping pass would look like: walk the room with the sensor
  once, post-process, get a static prior the agent localizes against. Sensor
  choice (Livox Mid-360) and the data-collection-then-post-process split are
  both directly applicable.
- **Feasibility:** Hardware ~$1.5k for the Livox Mid-360 alone. Build effort
  is ~1-2 weeks for hardware + a first usable map. **Not justified until there
  is a mobile platform to localize.**

## Sensor-class summary

| Class | Example | Range | Min range | Cost | Fits track |
|---|---|---|---|---|---|
| Structured-light depth | Intel RealSense D405 | 7-50 cm | 7 cm | ~$580 | (a) |
| ToF depth | Orbbec Femto Bolt / Mega | 0.25-5 m | ~25 cm | ~$400 | (a) (with caveats on min range) |
| Stereo + NN | Luxonis OAK-D SR | 0.2-2 m | 20 cm | ~$300 | (a) |
| Solid-state LIDAR | Livox Mid-360 | 0.1-40 m | 10 cm | ~$1,500 | (b) |
| Solid-state LIDAR | Unitree L1 / L2 | 0.1-30 m | 10 cm | ~$700-1,000 | (b) |
| Photogrammetry rig | OpenScan | cm-scale | n/a | DIY | one-off labware digitization |

LIDAR is the **wrong tool** for track (a). 10 cm minimum range covers most of
the SO-101 reach envelope as a dead zone, and angular resolution at 30 cm is
too coarse to resolve a tip rack edge. Depth cameras are the **wrong tool**
for track (b): FOV is too narrow for room-scale mapping in one pass.

## Track (a): workcell awareness — feasibility

- **Sensor:** RealSense D405 is the strongest fit. 7 cm minimum range, designed
  for short-range manipulation, well-supported (`pyrealsense2` on PyPI), used in
  the existing LeRobot ecosystem.
- **Software:** New `src/so101/perception/` module behind a `DepthSource`
  Protocol. ArUco / AprilTag (`opencv-contrib-python`) anchors deck and
  labware. `perception/deck_model.py` holds a small URDF or USD scene that the
  orchestrator queries via `is_clear(from, to)` before each scripted move.
- **Integration:** Composition over `DualArmController` and the orchestrator
  added in qte77/i3mega-pipettebot#120. Opt-in via `SO101_PERCEPTION=on`;
  default off, so existing behavior is preserved.
- **Test strategy:** Recorded depth frames + synthetic fiducial fixtures in
  `tests/perception/`. No hardware-gated tests in CI; live tests tagged
  `@pytest.mark.hardware`.
- **Effort:** ~1 week for driver + fiducial pipeline + first clearance check.
- **Blocking risk:** None. Depth cam is a $580 dependency; the rest is code.

## Track (b): lab-room SLAM + digital twin — feasibility

- **Sensor:** Livox Mid-360 (primary candidate) or Unitree L1/L2 (cheaper
  fallback). 360° × ~59° FOV, 40 m range, 10 cm min range — sized for indoor.
- **Data pipeline:**
  1. MANDEYE-style logger captures Livox frames + IMU during a single walk-around.
  2. HDMapping (or FAST-LIO / GLIM) post-processes to a georeferenced cloud.
  3. Conversion step: point cloud → USD scene (preferred — matches the Isaac /
     MuJoCo workflows already in the roadmap) or IFC (true BIM interop via
     IfcOpenShell, heavier dep tree).
  4. `perception/world_model.py` loads the scene at startup; planner consults
     it for waypoints and forbidden volumes.
  5. Online localization against the prior map (FAST-LIO2 odometry). SLAM on
     the fly only as a fallback.
- **BIM angle:** Worth distinguishing.
  - **USD digital twin** — pragmatic, code-friendly, what robotics tools speak.
  - **IFC / BIM** — useful only if the lab's facility-management data already
    lives in IFC, or if floor-plan handoff to other building systems is needed.
    Default to USD; treat IFC as a separate export.
- **Blocking risk:** Hard block on the existence of a mobile platform. With a
  fixed bench, track (a) covers the entire collision-relevant volume; (b) adds
  cost without unlocking new behavior. **Trigger to unblock:** first PR that
  introduces a wheeled base, gantry-on-rails, or AMR integration. Re-evaluate
  sensor choice at that point — the Livox / Unitree market moves quickly.
- **Effort:** ~1-2 weeks once unblocked, dominated by SLAM tuning and the
  USD/IFC conversion.

## 3D-printed mounts and fixtures

Both tracks need printed parts (sensor brackets, fiducial holders, calibration
targets). These live in the existing `src/hardware/` + `tools/cad/` pipeline —
no new tooling required. Track (a) needs a D405 bracket sized to the SO-101
wrist or to a fixed overhead pole; track (b) needs a Livox + IMU enclosure for
the MANDEYE-style logger. Mass and obstruction budget should be reviewed
against the existing payload limits before committing a design.

## Decision summary

- **Do now:** Track (a), gated by issue #perc-a.
- **Defer:** Track (b), captured in issue #perc-b, blocked on mobile platform.
- **Reject (for surroundings awareness):** Photogrammetry as a runtime sensor.
  Keep OpenScan in mind only for one-off labware digitization.

## Quick Refs

| Ref | URL |
|-----|-----|
| OpenScan | <https://openscan.eu> |
| 3D LIDAR topic | <https://github.com/topics/3d-lidar> |
| MANDEYE controller | <https://github.com/januszbedkowski/mandeye_controller> |
| HDMapping | <https://github.com/MapsHD/HDMapping> |
| FAST-LIO2 | <https://github.com/hku-mars/FAST_LIO> |
| GLIM | <https://github.com/koide3/glim> |
| Livox Mid-360 | <https://www.livoxtech.com/mid-360> |
| Unitree LIDAR | <https://shop.unitree.com/products/unitree-lidar> |
| Intel RealSense D405 | <https://www.intelrealsense.com/depth-camera-d405/> |
| Orbbec Femto Bolt | <https://www.orbbec.com/products/tof-camera/femto-bolt/> |
| Luxonis OAK-D SR | <https://shop.luxonis.com/products/oak-d-sr> |
| pyrealsense2 (PyPI) | <https://pypi.org/project/pyrealsense2/> |
| OpenCV ArUco docs | <https://docs.opencv.org/4.x/d5/dae/tutorial_aruco_detection.html> |
| OpenUSD | <https://openusd.org/> |
| IfcOpenShell | <https://ifcopenshell.org/> |
| MuJoCo | <https://mujoco.org/> |
| Isaac Sim | <https://developer.nvidia.com/isaac/sim> |

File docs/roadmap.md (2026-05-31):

---
title: Roadmap & Future Vision
purpose: Forward-looking direction — closed-loop 3D printing, autonomous tool genesis, VLM/embodied AI phases
authority: Vision (INFORMATIONAL — not requirements)
created: 2026-03-27
updated: 2026-05-31
---

# Roadmap: Closed-Loop Automation & Autonomous Tool Genesis

Long-term direction for so101-biolab-automation. For actionable prior art and research, see [research.md](research.md).

## Overview

Toward general-purpose voice/agent-to-print. This repo is the first showcase.

**Human loop** — voice/text → LLM → build123d/OpenSCAD → slicer → print → human inspects → iterate

**Agent loop** — goal spec → agent generates CAD → slicer validates → printer API → camera + VLM inspects → agent fixes → reprints autonomously

**Hardware bringup:** See [hardware/bringup.md](hardware/bringup.md) for the
standard 6-DOF SO-101 calibration + teleoperation procedure, and
[hardware/two-dof-pipette.md](hardware/two-dof-pipette.md) for the simplified
2-axis pipetting variant.

**Milestones:**

1. **Done** — build123d + CuraEngine CLI pipeline (`make render_parts`, `make check_prints`)
2. **Done** — **PrusaLink API integration** as the first concrete printer API in the stack. MK4 slicer profiles (production PLA, prototype, TPU) + upload/print curl examples in [docs/hardware/prusa-mk4-ops.md](hardware/prusa-mk4-ops.md). Bambu remains the target for the agent-loop's camera+VLM step; PrusaLink fills the gap for single-printer workflows today.
3. **Done** — **Scan-informed parametric CAD**. First scan-derived parts delivered: `dpette_multi_handle` + `dpette_ejector_lever` from a 1:1 mm Revopoint scan of the DLAB dPette+ (see `hardware/scans/dpette/`). `parts.json` now carries a `scan_source` field for queryable scan provenance.
4. **Next** — LLM-assisted build123d generation from text prompts + scan input
5. **Future** — Autonomous agent loop with Bambu camera + VLM print inspection
6. **Vision** — Closed-loop tool genesis: agent identifies missing tool → generates CAD (optionally from a fresh scan) → slices → prints → mounts via tool changer → validates with VLM — true self-evolving multi-tool

## Closed-Loop 3D Printing

### Human Loop (voice/text → print)

```text
Human (voice/text) → LLM → OpenSCAD → STL → Slicer → Print
       ↑                                          |
       └── human inspects, describes fix ──────────┘
```

Human describes a part or modification in natural language (via CC `/voice` or text). LLM generates OpenSCAD, slicer validates, human inspects result and iterates.

### Agent Loop (goal → autonomous design-print-inspect)

```text
Goal/Task spec ──→ Agent ──→ OpenSCAD → STL → Slicer validate
                     ↑                              |
                     |                         Printer API (MQTT)
                     |                              ↓
                     |                         Camera (RTSP/JPEG)
                     |                              ↓
                     └── VLM analyzes print ←───────┘
                         Agent adjusts design/params
```

Agent receives a goal (e.g., "print a plate holder fitting SBS 127.76x85.48mm with 0.5mm clearance, PLA+, must pass printability check"). Autonomously:

1. Generates OpenSCAD from spec
2. Validates via slicer CLI
3. Sends GCode to printer via MQTT API
4. Monitors print via camera feed (RTSP/JPEG)
5. VLM (vision-language model) analyzes camera frames for defects
6. On failure: agent adjusts design/params, re-slices, reprints

### Bambu camera + printer API (enables agent feedback)

- Built-in cameras: X1 (RTSP), A1/P1 (JPEG frames)
- Local MQTT: `<printer-ip>:8883`, topic `device/<serial>/report`
- Python: [`bambu-connect`](https://pypi.org/project/bambu-connect/), [`bambulabs-api`](https://pypi.org/project/bambulabs-api/)
- Cloud API: [`Bambu-Lab-Cloud-API`](https://github.com/coelacant1/Bambu-Lab-Cloud-API) (unofficial)

### Camera-based failure detection

| Tool | How | Printers |
|---|-----|---|
| [Obico](https://github.com/TheSpaghettiDetective/obico-server) | Vision model, 30-60s intervals, auto-pause | OctoPrint, Klipper, Bambu |
| [OctoEverywhere Gadget](https://octoeverywhere.com/gadget) | Neural net trained on millions of prints | OctoPrint |
| [PrintWatch](https://plugins.octoprint.org/plugins/printwatch/) | AI video feed, auto-pause | OctoPrint |

### LLM/VLM agent loops for 3D printing

| Project | Architecture | Result |
|---|---|---|
| [LLM-3D Print](https://arxiv.org/abs/2408.14307) | Multi-agent: supervisor + VLM image reasoning + planner + executor → camera → corrects → reprints | 5x structural integrity, expert-level error ID |
| [Build Great AI](https://zenml.io/llmops-database/llm-powered-3d-model-generation-for-3d-printing) | Text → LLaMA/GPT/Claude → OpenSCAD → STL | Hours to minutes for design |
| [CADialogue](https://www.sciencedirect.com/science/article/abs/pii/S0010448525001678) | Multimodal LLM: text + speech + images → parametric CAD | Conversational CAD |

### Related projects (LLM + CAD/print)

| Project | What | Relation to us |
|---|---|---|
| [ClaudeCAD](https://github.com/niklasmh/ClaudeCAD) | Claude + voice + web UI → STL download | Similar voice→CAD idea, web-only, no slicing or print control |
| [claude-3d-playground](https://github.com/ivanearisty/claude-3d-playground) | Claude Code for design, validate, slice | Closest competitor; no voice, no agent loop, no camera inspect |
| [openscad-agent](https://github.com/iancanderson/openscad-agent) | Claude Code agent for OpenSCAD modeling | Single-tool agent; no slicer, no print, no feedback loop |
| [CQAsk](https://github.com/OpenOrion/CQAsk) | LLM + CadQuery → STL/STEP with UI | Uses CadQuery not OpenSCAD; no print pipeline |
| [ScadLM](https://github.com/KrishKrosh/ScadLM) | Agentic AI + OpenSCAD generation | Early stage; no slicer validation or print control |
| [Text2CAD](https://github.com/SadilKhan/Text2CAD) | NeurIPS 2024: text → parametric CAD operations | Academic; 170K models dataset; no print integration |
| [text-2-cad](https://github.com/roberto-ceraolo/text-2-cad) | OpenAI + RAG over OpenSCAD docs → .scad | Early; similar LLM+OpenSCAD approach, minimal |
| [Speech-to-Reality](https://arxiv.org/html/2409.18390) | Voice → 3D generative AI → robotic assembly | See § "Autonomous Tool Genesis" for full analysis |

### MCP servers (integration layer)

| Server | What | Use for us |
|---|---|---|
| [OctoEverywhere MCP](https://github.com/OctoEverywhere/mcp) | Printer control, camera, AI failure detection (OctoPrint/Klipper/Bambu) | Agent loop: send jobs, read camera, pause on failure |
| [OpenSCAD MCP](https://www.pulsemcp.com/servers/jhacksman-openscad) | Generate 3D models from text/images via OpenSCAD | Alternative to direct CLI; Claude Desktop integration |
| [CADQuery MCP](https://github.com/rishigundakaram/cadquery-mcp-server) | CAD generation + STL/STEP export + SVG feedback | CadQuery path if needed |

**Key insight:** No project integrates all layers (voice → design → validate → print → camera+VLM inspect → agent fix). The MCP ecosystem provides the building blocks.

## Autonomous Tool Genesis (Self-Evolving Multi-Tool)

**Vision:** Robot identifies missing tool → agent generates CAD → prints → mounts via tool changer → validates with VLM → iterates. No existing system fully closes this loop as of mid-2026.

### Tool Genesis Loop

```text
Task requires unknown tool
       ↓
Agent detects capability gap
       ↓
VLM/LLM designs tool (CadQuery/OpenSCAD)
       ↓
Slicer validates → Printer fabricates
       ↓
Robot mounts via tool changer
       ↓
Execute task → VLM validates result
       ↓ (fail)
Agent adjusts design → reprints
```

### Closest Existing Systems

| Project | Year | Institution | What | Gap vs Full Loop |
|---|---|---|---|---|
| [RobotSmith](https://arxiv.org/abs/2506.14763) | 2025 | UMass + MIT | VLM proposes tool geometry, simulates trajectories, 3D-prints, deploys on real robot. 50% success. NeurIPS 2025. | **Closest overall.** Fabrication handoff is manual, no iterative reprinting. |
| [VLMgineer](https://arxiv.org/abs/2507.12644) | 2025 | UPenn | VLMs co-design tool geometry + action plan via evolutionary search. 12-task benchmark. | Co-optimization of design+use. No physical fabrication in loop. |
| [Ringwald et al.](https://arxiv.org/abs/2210.10015) | 2022 | TU Munich | Two robots + two 3D printers. Auto print → mount → test gripper fingertips. Fully automated fab-to-deploy. | **Best physical pipeline.** Uses predefined STLs, no LLM design or gap detection. |
| [MAMA BEAR](https://www.bu.edu/articles/2024/a-robot-on-a-mission) | 2018+ | Boston U | Autonomous robot running 3+ years. Designs via Bayesian opt → prints → crush-tests → iterates. 25K+ structures. | **Gold standard for design-fabricate-test loop.** Structures, not tools. |
| [RoboTool](https://arxiv.org/abs/2310.13065) | 2023 | CMU + DeepMind | LLM reasons about when to **manufacture** a new tool vs select existing. Tested on real robots. | Demonstrated manufacturing reasoning. No actual CAD gen or printing. |

### Enabling Research

| Project | Year | Institution | What | Relevance |
|---|---|---|---|---|
| [Learning to Design and Use Tools](https://arxiv.org/abs/2311.00754) | 2023 | Stanford / MIT | RL jointly learns designer policy (tool geometry) + controller policy (tool use). Zero-shot to unseen goals. CoRL 2023. | Joint design+control optimization — learns novel tool shapes. |
| [Speech to Reality](https://arxiv.org/abs/2409.18390) | 2025 | MIT CSAIL + DeepMind + Autodesk | Voice → LLM → 3D gen → robotic assembly. Builds furniture in ~5 min. ACM SCF '25 + NeurIPS. | Full prompt-to-physical-object loop (assembly, not printing). |
| [GAD (Generative AI + CAD)](https://link.springer.com/article/10.1007/s00170-025-15830-2) | 2025 | Springer | GPT-4o generates 3D models from text/images/voice → STL + G-code → direct to printer. | End-to-end text-to-print with printer integration. |
| [Generative AI for FreeCAD](https://arxiv.org/abs/2508.00843) | 2025 | Various | LLMs generate FreeCAD scripts from NL, iteratively refine on error feedback. | Directly applicable — parametric script gen for tool parts. |
| [CAD-LLM](https://www.research.autodesk.com/publications/ai-lab-cad-llm/) | 2024 | Autodesk Research | LLM generates parametric CAD from natural language. | Text-to-CAD backbone for fabrication pipeline. |
| [FiloBot](https://techxplore.com/news/2024-01-snake-robot-3d-body-longer.html) | 2024 | IIT Italy | Snake robot 3D-prints its own body to grow longer (FDM). Responds to stimuli. | Robot that literally fabricates itself — narrow but novel. |

### What's Missing (Open Problems)

No single system combines all six steps:

1. **Capability gap detection** — robot identifies it lacks a tool for a task
2. **LLM/VLM-driven CAD** — designs a novel tool parametrically
3. **Automated fabrication** — prints with quality monitoring ([LLM-3D Print](https://arxiv.org/abs/2408.14307))
4. **Robotic tool mounting** — picks up via quick-exchange (Ringwald has this)
5. **Task execution + validation** — uses tool, verifies success (RobotSmith has this)
6. **Iterative refinement** — redesigns and reprints on failure (MAMA BEAR has this for structures)

**Our position:** Steps 1-2-3 via build123d + PrusaSlicer + Bambu printer. Step 4 via SO-101 tool changer. Steps 5-6 via VLM camera loop. Assembling these subsystems into a unified pipeline is the frontier.

## VLM + Embodied AI for Hands-Off Autonomous Operation

### Operation Modes (Progressive)

```text
Phase 1 (current)    → Stub mode, coordinate commands, remote dashboard
Phase 2 (hardware)   → Teleoperation + ACT policy training, in-situ operator
Phase 3 (remote)     → Remote-controlled via dashboard, human oversight
Phase 4 (vision)     → Wrist camera visual servoing, closed-loop correction
Phase 5 (autonomous) → VLM task planning + embodied execution, long-running unattended
```

### Why VLM + Embodied AI Is Necessary for Phase 4-5

- **Sub-mm alignment**: SO-101 open-loop repeatability (~1-2mm) insufficient for tip press-fit. Visual servoing closes the gap.
- **Meniscus detection**: Liquid level tracking during aspiration requires real-time vision.
- **Drift compensation**: Plate/rack positions shift during long runs. Can't rely on fixed coordinates.
- **Tool verification**: Confirm tip attached, tool engaged, plate seated — visual confirmation.
- **Task planning**: "Pipette row A with 25µL from reagent in fridge" → decompose into sub-tasks autonomously.
- **Error recovery**: Detect dropped tip, missed well, spill — re-plan and retry without human.

### Key Technologies

| Technology | Purpose | Reference |
|---|---|---|
| Real-time VLM | Task planning from natural language + visual scene understanding | [OpenVLA](https://arxiv.org/abs/2406.09246) (2024), [RT-2](https://arxiv.org/abs/2307.15818) (2023) |
| Embodied AI policy | End-to-end visuomotor control (camera → joint actions) | ACT/LeRobot (in stack), [π0](https://arxiv.org/abs/2410.24164) (Physical Intelligence, 2024) |
| Visual servoing | Sub-mm tip/well alignment from wrist camera | OpenCV + ArUco, or learned visual features |
| Force estimation | Tip press-fit without F/T sensor | [Bi-ACT](https://arxiv.org/abs/2401.17698), [FTACT](https://arxiv.org/abs/2509.23112) |
| Human-in-the-loop | Remote operator corrects policy; corrections become training data | [RoboCopilot](https://arxiv.org/abs/2503.07771) (2025) |
| Sim-to-real | Train in simulation, deploy zero-shot | [AutoBio](https://arxiv.org/abs/2505.14030), [MatteriX](https://arxiv.org/abs/2601.13232), [LeIsaac](https://huggingface.co/docs/lerobot/envhub_leisaac) |
| Data amplification | 20 real demos → 2000 synthetic | [DexMimicGen](https://arxiv.org/abs/2410.24185) (NVIDIA, open-source) |

### Long-Running Autonomous Execution

For unattended multi-hour runs (e.g., 96-well plate with replicates, overnight incubation cycles):

- **Watchdog**: SafetyMonitor already parks arms on heartbeat timeout (5s)
- **Remote dashboard**: WebSocket commands for pause/resume/e-stop from anywhere
- **State persistence**: Log every aspirate/dispense to a run journal (well, volume, timestamp)
- **Error budget**: Define acceptable failure rate (e.g., ≤2 missed wells per plate) before auto-abort
- **Checkpoint/resume**: If interrupted, resume from last successful well (journal-based)

### Hardware Additions for Phase 4-5

- High-res wrist cameras (in BOM: 32x32mm UVC modules)
- Overhead camera with ArUco workspace calibration
- Optional: depth camera ([RealSense D405 mount](https://github.com/TheRobotStudio/SO-ARM100#5-wristmount-cameras)) for 3D tip tracking
- Optional: wrist F/T sensor for contact-aware manipulation

### Spatial Awareness — Workcell + Lab-Room

Two tracks, two scales, two sensor classes. Full landscape survey:
[outlook-perception-lidar.md](outlook-perception-lidar.md).

| Track | Scale | Sensor | Phase fit | Status |
|---|---|---|---|---|
| (a) Workcell awareness | <= 500 mm | Short-range depth (D405) + ArUco/AprilTag fiducials | Phase 4 — complements wrist-camera visual servoing | #170 — proposed |
| (b) Lab-room SLAM + digital twin | 3-15 m | 360 deg LIDAR (Livox Mid-360 / Unitree L1) + IMU, MANDEYE-style logger, USD or IFC export | Phase 5+ — requires mobile platform | #171 — blocked on mobile base |

Capability -> tool mapping (why one sensor class does not replace the others):

| Need | Right tool |
|---|---|
| Pre-move collision check, deck occupancy | Short-range depth (D405) or LIDAR — depth wins on cost + min-range |
| Labware identity, barcode, QC, meniscus | RGB camera, wrist or overhead. No substitute. |
| Room-scale navigation (mobile base) | LIDAR (track (b) above) |
| Protocol selection, error recovery, "what did the user mean" | LLM / VLM |

Design intent:

- Depth + RGB (D405) and LIDAR are **complementary, not alternatives**.
  LIDAR is wrong for the workcell (10 cm min range, no labware identity);
  cameras are wrong for room-scale (FOV too narrow).
- VLM / LLM is a **separate axis** from the depth / LIDAR stack — it covers
  identity, QC, and protocol selection. Geometry sensing does not replace
  the VLM, and the VLM does not replace geometry sensing.
- Track (a) plugs into the named-position orchestrator from
  qte77/i3mega-pipettebot#120 as a pre-move clearance check; track (b)
  loads a prior map at startup for online localization.

## Near-Term Actions (When Hardware Arrives)

1. Use [AIDASLab bimanual fork](https://github.com/AIDASLab/lerobot-so101-bimanual) for dual-arm setup
2. Apply Loctite 242 to motor 5 screws on all arms
3. Print [reinforced trigger](https://www.printables.com/model/1323562) for leader arm
4. Print [parallel gripper](https://makerworld.com/en/models/1549112) as pipette holder base
5. Port Berkeley tool changer cone to SO-101 wrist dimensions
6. Record 50 episodes per task using decomposed motion phases
7. Train ACT via LeRobot; evaluate on AutoBio benchmark
8. Implement USB watchdog for long-run stability

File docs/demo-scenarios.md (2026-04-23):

---
title: Demo Scenarios
purpose: Runnable commands and expected output for every use case (UC1-5)
authority: Operations (AUTHORITY)
created: 2026-03-27
updated: 2026-03-27
---

# Demo Scenarios

How to run and verify each use case (UC). All commands work in stub mode (no hardware).

## Prerequisites

```bash
make setup_all      # install all dependencies + tools
make serve          # (optional) start dashboard on :8080
```

**Physical demo setup (optional).** The pipetting use cases (UC1, UC5) can be demonstrated on real hardware once the printed parts and pipette are mounted. The DLAB dPette+ 8-channel mount is the primary configuration — see [../src/hardware/README.md](../src/hardware/README.md#dpette-8-channel-mount-replaces-so-101-gripper-jaws) for the assembly and print settings, [../docs/hardware/BOM.md](hardware/BOM.md) for the parts list, and [prusa-mk4-ops.md](hardware/prusa-mk4-ops.md) for uploading gcode to a Prusa MK4 via PrusaLink. All demo commands below also run cleanly in **stub mode** without any hardware.

## UC1: Pipette a 96-Well Plate

### UC1.1: Single Well

Aspirate 50 µL from trough, dispense to well A1.

```bash
uv run so101-demo --use-case uc1_single --well A1 --volume 50
```

Expected output:

```text
[UC1] Move arm_a → TROUGH (200.0, 0.0 mm)
[UC1] Aspirate 50.0 µL
Moving arm_a to well A1 (14.38, 11.24 mm)
[UC1] Dispense 50.0 µL → A1
Demo complete.
```

### UC1.2: Row

Pipette all 12 wells in row A at 25 µL each.

```bash
uv run so101-demo --use-case uc1_row --row A --volume 25
```

Expected: 12 aspirate/dispense cycles (A1 through A12).

### UC1.3: Column

Pipette all 8 wells in column 1 at 20 µL each.

```bash
uv run so101-demo --use-case uc1_col --col 1 --volume 20
```

Expected: 8 aspirate/dispense cycles (A1 through H1).

### UC1.4: Full Plate

Pipette all 96 wells at 20 µL each.

```bash
uv run so101-demo --use-case uc1_full --volume 20
```

Expected: 96 aspirate/dispense cycles. Each well gets an independent aspirate→dispense so the pipette never overflows its 200 µL capacity.

## UC2: Fridge Operations

Open fridge with hook tool, swap to gripper, grab item, move to park.

```bash
uv run so101-demo --use-case uc2
```

Expected output:

```text
[UC2] Starting fridge sequence
Tool changed to fridge_hook
[UC2] Approach fridge
[UC2] Engage hook — pull door
[UC2] Release hook — door open
Tool changed to gripper
[UC2] Grab item from fridge
Parking arm arm_a
Parking arm arm_b
[UC2] Fridge sequence complete — item at park position
```

## UC3: Tool Interchange

Cycle through all tools: pipette → gripper → fridge hook → gripper.

```bash
uv run so101-demo --use-case uc3
```

Expected output:

```text
[UC3] Starting tool cycle: ['pipette', 'gripper', 'fridge_hook', 'gripper']
[UC3] Equipped pipette
[UC3] Equipped gripper
[UC3] Equipped fridge_hook
[UC3] Equipped gripper
```

## UC4: Full Demo (All Use Cases)

Runs UC1.1 + UC1.2 (row A) + UC1.2 (column 1) + UC2 + UC3 in sequence.

```bash
uv run so101-demo
```

Or equivalently:

```bash
uv run so101-demo --use-case all
```

## Dashboard Demo

Start the dashboard and trigger the workflow via WebSocket:

```bash
make serve_dashboard
```

Open `http://localhost:8080` in a browser. Click "Run Demo" button. The full UC4 sequence runs in the background. Check `GET /api/status` for current state.

Or via curl:

```bash
# Check status
curl http://localhost:8080/api/status

# Trigger e-stop via WebSocket (using websocat)
echo '{"command": "e_stop"}' | websocat ws://localhost:8080/ws
```

## Verification

All scenarios are covered by automated tests:

```bash
uv run pytest tests/test_workflow.py -v    # workflow use case tests
uv run pytest tests/test_dashboard.py -v   # dashboard integration tests
uv run pytest -q                           # full suite
```

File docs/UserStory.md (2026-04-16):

---
title: User Stories
purpose: Acceptance criteria for use cases UC1-5 (pipetting, fridge, tool change, remote oversight, gantry) + developer stories
authority: Acceptance criteria (AUTHORITY)
created: 2026-03-27
updated: 2026-04-09
---

# User Stories & Acceptance Criteria

Each use case (UC) groups one or more user stories (US) with acceptance criteria.

## Roles

- **Lab researcher** — operates the system to automate pipetting and sample handling
- **Remote operator** — monitors and controls the system via web dashboard
- **Developer** — extends the system with new workflows and hardware support

## Pipetting (UC1)

### US-1.1: Single Well Pipetting

> As a **lab researcher**, I want to pipette a specific volume from the reagent trough to a single well, so that I can prepare individual samples.

**Acceptance criteria:**

- [ ] Specify target well by name (e.g., A1, H12) and volume in µL
- [ ] Arm moves to trough, aspirates, moves to well, dispenses
- [ ] Pipette fill returns to 0 after dispense
- [ ] Invalid well name raises clear error

**Command:** `uv run so101-demo --use-case uc1_single --well A1 --volume 50`

### US-1.2: Row/Column Pipetting

> As a **lab researcher**, I want to pipette an entire row or column in one command, so that I can prepare a set of samples without repeating commands.

**Acceptance criteria:**

- [ ] Specify row (A-H) or column (1-12) and volume per well
- [ ] All wells in the row/column receive the specified volume
- [ ] Each well gets an independent aspirate→dispense cycle
- [ ] Invalid row/column raises clear error

**Commands:**

- `uv run so101-demo --use-case uc1_row --row A --volume 25`
- `uv run so101-demo --use-case uc1_col --col 1 --volume 20`

### US-1.3: Full Plate Pipetting

> As a **lab researcher**, I want to pipette all 96 wells of a plate in one command, so that I can prepare a full experiment plate hands-free.

**Acceptance criteria:**

- [ ] All 96 wells (A1 through H12) receive the specified volume
- [ ] Pipette never overflows (each well is an independent aspirate→dispense)
- [ ] Sequence follows row-major order (A1, A2, ..., H12)

**Command:** `uv run so101-demo --use-case uc1_full --volume 20`

## Fridge Operations (UC2)

### US-2.1: Retrieve Item from Fridge

> As a **lab researcher**, I want the arm to open a fridge, grab a reagent plate, and move it to the workspace, so that I can access cold-stored samples without manual intervention.

**Acceptance criteria:**

- [ ] Arm equips fridge hook tool
- [ ] Hook engages fridge door handle, pulls open
- [ ] Arm swaps to gripper tool
- [ ] Gripper grabs item from fridge shelf
- [ ] Arm moves item to park (safe workspace) position

**Command:** `uv run so101-demo --use-case uc2`

## Tool Interchange (UC3)

### US-3.1: Swap Tools Autonomously

> As a **lab researcher**, I want the arm to change its end-effector without manual intervention, so that it can switch between pipetting and sample transport tasks.

**Acceptance criteria:**

- [ ] Arm returns current tool to magnetic dock station
- [ ] Arm picks up target tool from dock
- [ ] Supports 3 tools: pipette, gripper, fridge hook
- [ ] Changing to the already-equipped tool is a no-op

**Command:** `uv run so101-demo --use-case uc3`

## Remote Oversight (UC4)

### US-4.1: Monitor and Control via Dashboard

> As a **remote operator**, I want to view system status and send commands from a web browser, so that I can oversee and intervene in lab operations from anywhere.

**Acceptance criteria:**

- [ ] Dashboard accessible at `http://localhost:8080`
- [ ] Live status: mode, e-stop state, arm connection, arm IDs
- [ ] Commands via WebSocket: e-stop, heartbeat, pause, resume, target well, run workflow
- [ ] E-stop triggers SafetyMonitor and parks all arms
- [ ] Heartbeat resets watchdog timer (5s timeout → auto-park)

**Command:** `make serve_dashboard`

### US-4.2: Run Full Demo Remotely

> As a **remote operator**, I want to trigger the full demo sequence from the dashboard, so that I can demonstrate all capabilities without CLI access.

**Acceptance criteria:**

- [ ] "Run Demo" button in dashboard triggers UC4 (all use cases)
- [ ] Workflow runs in background (dashboard stays responsive)
- [ ] Status endpoint reflects "running" mode during execution

## Gantry Pipetting (UC5)

### US-5.0: Gantry-Based Pipetting

> As a **lab researcher**, I want to pipette using the simpler XZ gantry instead of the SO-101 arm, so that I can run repetitive pipetting at fixed positions with minimal setup.

**Acceptance criteria:**

- [ ] Gantry moves to source position, lowers, pipette aspirates, raises
- [ ] Gantry moves to destination position, lowers, pipette dispenses, raises
- [ ] Works with any PipetteProtocol backend (DigitalPipette or ElectronicPipette)
- [ ] Strip mode pipettes multiple destinations from a single source
- [ ] Invalid position name raises clear error

**Commands:**

- `uv run so101-demo --use-case uc5_gantry --volume 50`

## Developer Stories

### US-5.1: Extend with New Workflow

> As a **developer**, I want to add a new use case by composing existing modules, so that I can automate new lab tasks without modifying core modules.

**Acceptance criteria:**

- [ ] New workflow composes existing modules via `create_workflow_context()`
- [ ] No modifications to core modules (`arms.py`, `pipette.py`, `plate.py`, etc.)
- [ ] New workflow has corresponding tests in `tests/`

See [docs/architecture.md](architecture.md) for module API and composition patterns.

### US-5.2: Run All Tests Without Hardware

> As a **developer**, I want all tests to pass without physical hardware attached, so that I can develop and CI/CD in any environment.

**Acceptance criteria:**

- [ ] `uv run pytest` passes on any machine with Python 3.10+
- [ ] No `@pytest.mark.hardware` tests run by default
- [ ] Stub mode automatically activates when lerobot/pyserial/cv2 unavailable

**Command:** `make validate`

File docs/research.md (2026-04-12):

---
title: Research — Prior Art & Literature
purpose: Community designs, academic papers, open-source projects, and cross-cutting insights for SO-101 biolab automation
authority: Research (INFORMATIONAL — not requirements)
sources: MakerWorld, Thingiverse, Printables, GitHub, arXiv, bioRxiv, Reddit, MakerForge, UZH, EPFL
created: 2026-03-27
updated: 2026-04-12
---

# Research: Prior Art & Literature

## Related Docs

| Topic | Doc |
|---|-----|
| Hardware inventory & reverse engineering | [outlook-integrations.md](outlook-integrations.md) |
| Pipetting platforms (3D printers, CNC) | [outlook-printer-platforms.md](outlook-printer-platforms.md) |
| Ceiling-mounted SO-101 | [outlook-ceiling-rail.md](outlook-ceiling-rail.md) |
| CAD, slicers, simulation | [hardware/cad-tooling.md](hardware/cad-tooling.md) |
| PCR use case & acceptance criteria | [UserStory.md](UserStory.md) |
| Future vision & roadmap | [roadmap.md](roadmap.md) |

## Key Finding: No SO-101 Pipette End Effector Exists

No community design for a pipette attachment specifically for SO-101. This is an original contribution opportunity.

## Hardware Enhancements (3D-Printed)

| Design | Source | Date | Relevance |
|---|---|---|---|
| [Parallel Gripper for SO-101](https://makerworld.com/en/models/1549112) | MakerWorld (energiazero.org) | 2025-06 | Direct SO-101 wrist replacement. Adapt jaws for pipette holding. CAD: [GrabCAD](https://grabcad.com/library/standard-open-so-101-arms-with-parallel-gripper-1) |
| [TPU Grip for SO-100/101](https://www.thingiverse.com/thing:7153144) | Thingiverse (NekoMaker) | 2025-09 | Compliant fingertips for smooth objects (pipette barrels, plates). |
| [Silicone Gripper Tip Mold](https://www.thingiverse.com/thing:7152864) | Thingiverse (NekoMaker) | 2025-09 | Cast silicone tips for delicate labware handling. |
| [Reinforced Trigger](https://www.printables.com/model/1323562) | Printables (Chitoku) | 2025-06 | Fixes leader arm trigger breakage. **Apply Loctite 242 to motor 5 screw.** |
| [Bambu-Optimized SO-101](https://makerworld.com/en/models/1399268) | MakerWorld (manfromwest) | 2025-05 | Best SO-101 print files for Bambu. Camera mount provisions. |
| [AB-SO-BOT](https://github.com/Mr-C4T/AB-SO-BOT) | GitHub (54 stars) | 2025 | Aluminium body upgrade with RealSense mounts. |
| [WH148 Leader Arm](https://www.thingiverse.com/thing:7041540) | Thingiverse (xuyuan) | 2025-05 | Cheaper potentiometer-based leader arm. |
| [SO-101 Fin-Ray Gripper](https://makerworld.com/en/models/2075813) | MakerWorld (GauravMM) | 2025-12 | Compliant gripper for delicate/oddly-shaped objects. TPU 95A. |
| [SO-101 Parallel Gripper](https://github.com/roboninecom/SO-ARM100-101-Parallel-Gripper) | GitHub (Robonine) | 2026-03 | 1.5kg payload, 100.5mm stroke, $76. Open-source STL + code. |
| [XLeRobot](https://github.com/Vector-Wangel/XLeRobot) | GitHub ([docs](https://xlerobot.readthedocs.io)) | 2025 | Dual SO-101 on mobile base (LeKiwi). $660. URDFs + ManiSkill sim. 600-1000g payload/arm. |

## Tool Changer Design

**Primary source: [Berkeley Passive Tool Changer](https://goldberg.berkeley.edu/pubs/CASE2018-ron-tool-changer-submitted.pdf)**
**Repo: [BerkeleyAutomation/RobotToolChanger](https://github.com/BerkeleyAutomation/RobotToolChanger)** (branch: `tool-changer`)

**What we reuse directly:**

- Design geometry: 10 deg truncated cone angle, 5N magnets, spring-loaded dowel pins
- 3-part architecture: robot-side adapter, tool-side base, parking housing
- STL reference: 3 dirs (robot component, tool component, tool housing) — adapt dimensions from ABB YuMi flange to SO-101 wrist flange
- Passive locking principle: no power, no data through the tool interface
- ArUco marker guidance idea from paper's failure analysis (positioning errors, not mechanism)

**What we adapt:**

- Flange interface: redesign robot-side adapter for SO-101 motor 5 horn mount (M3 screw pattern, ~25mm diameter)
- Tool parking rack: design for 3 tools side-by-side at fixed workspace position
- Cable routing: add flat flex cable channel for pipette power (not in Berkeley design)

**License note:** Berkeley repo has no stated license. Use paper's design principles and our own STL geometry.

## Open-Source Liquid Handling Projects

| Project | URL | License | Date | What We Reuse |
|---|-----|---|---|---|
| [digital-pipette-v2](https://github.com/ac-rad/digital-pipette-v2) | GitHub | CC BY 4.0 + MIT | v2.0.0, 2025-11 | **Option A (DIY).** 5 STL parts, Arduino firmware, Python controller, Actuonix L16 actuator, full BOM. |
| [FINDUS](https://github.com/FBarthels/FINDUS) | GitHub | GPL-3.0 | 2020 ([paper](https://doi.org/10.1177/2472630319877374)) | Calibration procedure (<0.3% error). Tip-fit validation method. |
| [OTTO](https://github.com/DrD-Flo/OTTO) | GitHub | MIT | 2023 | Tip pickup geometry (insertion angle, force). Ejection mechanism. |
| [Sidekick](https://github.com/rodolfokeesey/Liquid-Handler) | GitHub | CERN-OHL-S v2 | 2022 ([paper](https://doi.org/10.1016/j.ohx.2022.e00319)) | SBS plate addressing geometry. 10uL solenoid pump alternative. |
| [GormleyLab](https://github.com/GormleyLab/Pipette-Liquid-Handler) | GitHub | MIT | 2025 | Bluetooth Integra pipette Python interface (`liquidhandler.py`). |
| [MULA](https://www.printables.com/model/1019242) | Printables | open | 2024 ([paper](https://doi.org/10.1016/j.ohx.2024.e00075)) | Gastight syringe mechanism. CAD on [Mendeley](https://data.mendeley.com/datasets/3m3t4f9ft3). |
| [OLA](https://docs.openlabautomata.xyz/) | Website | open | active | Community hub. Protocol sharing. |
| [PHIL](https://github.com/CSDGroup/PHIL) | GitHub | MIT | 2022 ([Nature Comms](https://www.nature.com/articles/s41467-022-30643-7)) | ETH Zurich. Personal pipetting robot. Tip management, media exchange, live-cell compatible. |
| [PyLabRobot](https://github.com/PyLabRobot/pylabrobot) | GitHub | Apache-2.0 | 2023 ([bioRxiv](https://www.biorxiv.org/content/10.1101/2023.07.10.547733)) | MIT Media Lab. Hardware-agnostic liquid handling. Write SO-101 backend driver ([#63](https://github.com/qte77/so101-biolab-automation/issues/63)). |
| [OptoBot](https://github.com/nicolaegues/OptoBot) | GitHub | — | 2024 | OT-2 + Python for automated experimental optimization loops. Closed-loop observe-decide-pipette pattern. |
| [OT-2 Plate Handler](https://doi.org/10.26434/chemrxiv-2025-n95kk) | ChemRxiv | — | 2025 (Bolt et al.) | 3D-printed robotic claw for Opentrons OT-2. Plate gripping geometry + positioning tolerances reusable. |

## Bimanual SO-101 Support

**[AIDASLab/lerobot-so101-bimanual](https://github.com/AIDASLab/lerobot-so101-bimanual)** (2026-01, 5 stars) — Drop-in LeRobot fork with `bi_so101_follower`/`bi_so101_leader` types. Calibration, teleoperation, recording all work dual-arm. **Use this instead of patching upstream.**

## Commercial References

### Andrew+ (Waters/Andrew Alliance) — [UZH page](https://www.zmb.uzh.ch/en/Available-Systems/SamplePreparationInstruments/Andrew-%2C-The-Pipetting-Robot.html)

- Cartesian gantry + interchangeable electronic pipettes (single/8-channel)
- Modular "Domino" snap-in accessories (heater/shaker, cooled racks, tip racks)
- OneLab cloud protocol software (drag-and-drop)
- Lessons: modular workspace with fixed slot positions; separate pipettes by volume range; 8-channel head for 96-well efficiency

### Sartorius Electronic Pipettes — [product page](https://www.sartorius.com/en/products/pipetting/electronic-pipettes)

- Picus 2: single/multi-channel, Bluetooth, programmable protocols
- Future integration target for SO-101

## Community Resources

- [MakerForge SO-101 guide](https://www.makerforge.tech/posts/seeed-so101/) — servo calibration, port detection, teleoperation setup
- [Seeed Studio SO-101 wiki](https://wiki.seeedstudio.com/lerobot_so100m/) — reComputer Jetson + SO-101 kits
- [PyLabRobot 2025 roadmap](http://discuss.pylabrobot.org/t/plr-dev-roadmap-2025-q1-q2/143) — extending to robotic arms (directly relevant)

## Known Hardware Issues

- **Gripper screw loosening** (motor 5) — apply Loctite 242/243 before long runs
- **USB disconnect during teleoperation** ([lerobot #3131](https://github.com/huggingface/lerobot/issues/3131)) — implement reconnect watchdog
- **Pipetting motion** should be decomposed into discrete phases for training (approach, insert tip, aspirate, move, dispense, eject)
- **50+ episodes minimum** per task, deliberate slow motions, 80k+ training steps

## Academic Papers

**What we reuse from papers:**

- **AutoBio**: open-source eval harness at `autobio-bench/AutoBio` — validate our policies against standard bio-lab tasks
- **DexMimicGen**: NVIDIA data amplification — 20 real demos to 2000 synthetic for ACT training
- **ArticuBot**: pre-trained fridge/door policy — zero-shot transfer for UC2, skip real fridge demos
- **InterACT/MoE-ACT**: replace vanilla ACT with inter-arm attention for bimanual pipetting
- **Tool-as-Interface**: collect pipetting demos from human video instead of robot teleoperation
- **Echo**: open-source force-feedback teleoperation — improve demo quality for tip press-fit
- **RoboCopilot**: human-in-the-loop correction loop — lab tech intervenes, corrections become training data
- **AIDASLab bimanual fork**: drop-in dual SO-101 support

### ETH / EPFL Lab Automation

| Paper | Year | Institution | Key Finding |
|---|---|---|---|
| [PHIL](https://www.nature.com/articles/s41467-022-30643-7) | 2022 | ETH Zurich (Dettinger et al.) | Open-source personal pipetting robot. MIT. Tip management, media exchange. **Repo: [CSDGroup/PHIL](https://github.com/CSDGroup/PHIL)** |
| [SIMO](https://doi.org/10.3389/frobt.2024.1462717) | 2025 | EPFL (Scamarcio et al.) | Bi-manual robot (ABB GoFa), vision + tactile, 1.2mm accuracy, 95%+ success. Sets accuracy benchmark. |

### General Lab Automation

| Paper | Year | Key Finding |
|---|---|---|
| [RoboCulture](https://arxiv.org/abs/2505.14941) | 2025 | Complete robotics platform for bio experiments. Aspuru-Guzik group (Toronto). |
| [AutoBio](https://arxiv.org/abs/2505.14030) | 2025 | Simulation benchmark for bio-lab tasks. Open-source eval harness. |
| [MatteriX](https://arxiv.org/abs/2601.13232) | 2026 | Digital twin for chemistry lab. Sim-to-real for pipetting. |
| [Microplate Handling Accuracy](https://www.biorxiv.org/content/10.1101/2023.12.29.573685v1) | 2024 | Positioning tolerance for 96-well plate grasping. |
| [Open Liquid Handler](https://www.biorxiv.org/content/10.64898/2026.03.02.709168v1) | 2026 | Industry-grade open-source liquid handler. PyLabRobot-compatible. |
| [Keyframe-Guided Rewards](https://arxiv.org/abs/2603.00719) | 2026 | RL reward shaping for long-horizon lab tasks. |
| [BioMARS](https://arxiv.org/abs/2507.01485) | 2025 | Multi-agent robot system for autonomous bio experiments. |
| [Dual Demonstration](https://arxiv.org/abs/2506.11384) | 2025 | Teaches end-effector AND jig operations simultaneously. |
| [Cutting the Cord](https://arxiv.org/abs/2603.09051) | 2026 | GPU-accelerated bimanual mobile manipulation on LeRobot/XLeRobot. |

### Imitation Learning (ACT & Bimanual)

| Paper | Year | Key Finding |
|---|---|---|
| [ALOHA/ACT](https://arxiv.org/abs/2304.13705) | 2023 | Our training framework. 50 demos/task, low-cost bimanual. |
| [LeRobot](https://arxiv.org/abs/2602.22818) | 2026 | Our stack's authoritative reference. ICLR 2026. |
| [ALOHA Unleashed](https://arxiv.org/abs/2410.13126) | 2024 | More data > bigger model. DeepMind validation of ACT ceiling. |
| [InterACT](https://arxiv.org/abs/2409.07914) | 2024 | Hierarchical attention for inter-arm dependencies. |
| [MoE-ACT](https://arxiv.org/abs/2603.15265) | 2026 | One multi-task model via MoE. 5+ tasks without per-task training. |
| [DexMimicGen](https://arxiv.org/abs/2410.24185) | 2024 | 20 demos to 2000 synthetic. NVIDIA open-source. |
| [X-IL](https://arxiv.org/abs/2502.12330) | 2025 | Systematic policy architecture comparison. |
| [Bi-ACT](https://arxiv.org/abs/2401.17698) | 2024 | Bilateral force-feedback ACT. Contact-rich tasks. |
| [FTACT](https://arxiv.org/abs/2509.23112) | 2025 | Force-torque aware ACT. F/T sensor in observation space. |
| [Bimanual ACT](https://arxiv.org/abs/2503.13916) | 2025 | ACT + inter-arm coordination module. AIST Japan. |

### Tool Use & Door Opening

| Paper | Year | Key Finding |
|---|---|---|
| [Tool-as-Interface](https://arxiv.org/abs/2504.04612) | 2025 | Learn from human tool-use video, not robot demos. |
| [FUNCTO](https://arxiv.org/abs/2502.11744) | 2025 | One-shot tool manipulation. Generalizes across variants. |
| [ArticuBot](https://arxiv.org/abs/2503.03045) | 2025 | Universal door/fridge policy. Zero-shot real transfer. |
| [UniDoorManip](https://arxiv.org/abs/2403.02604) | 2024 | Universal door policy (pull, push, sliding). |

### Data Collection

| Paper | Year | Key Finding |
|---|---|---|
| [YOTO](https://arxiv.org/abs/2501.14208) | 2025 | One-shot bimanual from video. Near-zero demo cost. |
| [Echo](https://arxiv.org/abs/2504.07939) | 2025 | Force-feedback teleoperation. Open-source. |
| [RoboCopilot](https://arxiv.org/abs/2503.07771) | 2025 | Human-in-the-loop correction. Interventions become training data. |
| [GELLO](https://arxiv.org/abs/2309.13037) | 2023 | Low-cost replica-arm teleoperation (UC Berkeley). |
| [Taming VR Teleoperation](https://arxiv.org/abs/2508.14542) | 2025 | VR-based bimanual demo collection. Less operator fatigue. |
| [Opening Articulated Structures](https://arxiv.org/abs/2402.17767) | 2024 | Door/fridge opening without pre-mapped kinematics. |

## Cross-Cutting Insights

1. **Data > model complexity** — 50+ demos per task, amplify with DexMimicGen
2. **Force feedback is the main gap** — SO-101 has no wrist F/T sensor; biggest reliability risk for pipette tip press-fit
3. **Sim-to-real works for fridge/door** — ArticuBot demonstrates zero-shot transfer; may not need real demos for UC2
4. **Decompose pipetting into phases** — approach, insert tip, aspirate, dispense, eject. Train per-phase or use keyframe rewards
5. **Bimanual needs inter-arm attention** — vanilla ACT struggles with coupled coordination; use InterACT or MoE-ACT
6. **PyLabRobot backend driver** — writing one for SO-101 makes all existing protocols work on our arms ([#63](https://github.com/qte77/so101-biolab-automation/issues/63))
7. **8-channel pipette head** — 8x efficiency for 96-well work; design as a specialized end-effector
8. **Tool genesis is the frontier** — subsystems exist (LLM-to-CAD, auto-print, tool changing, VLM validation) but no one has closed the full loop yet (see [roadmap.md](roadmap.md#autonomous-tool-genesis-self-evolving-multi-tool))

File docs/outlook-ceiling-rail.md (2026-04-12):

---
title: "Outlook: Ceiling-Mounted SO-101 on Linear Rail"
purpose: Feasibility study for inverted SO-101 arm on ceiling gantry — mechanical, software, safety
authority: Research (INFORMATIONAL — not requirements)
created: 2026-04-12
updated: 2026-04-12
---

# Outlook: Ceiling-Mounted SO-101 on Linear Rail

## Concept

Mount an SO-101 arm inverted from a ceiling-mounted linear rail, freeing the
entire bench surface. The arm approaches plates, Bento Lab, and reagents from
above — a natural orientation for pipetting and plate handling.

## Mechanical Feasibility

STS3215 servos (30 kg-cm Pro, 1:345 gear reduction) can handle inverted
operation, with caveats:

- **Backlash amplification** — gravity pulls through gear backlash zones
  instead of preloading against them, increasing end-effector positional error.
- **Sustained holding torque** — base and shoulder servos see continuous load
  rather than intermittent peaks.
- **3D-printed joint stress** — PLA/PETG joints designed for compression loads
  experience tension/hanging loads when inverted. Shoulder joint is the
  critical failure point.

### Required Modifications

- Metal base plate (aluminum or carbon fiber)
- Metal shoulder bracket
- Anti-backlash spring on wrist
- Secure bolt fasteners replacing press-fits
- Safety cable/lanyard to rail (redundant fall protection)

## Rail / Gantry Options

| System | Payload | Span | Drive | Cost (1 m) | Python Control |
|---|---|---|---|---|---|
| OpenBuilds C-Beam + XLarge cart | ~5 kg | ~2 m | GT2 belt | ~$80-150 | `grbl-streamer` (PyPI) or `pyserial` |
| igus drylin W | 5-15 kg | 3 m | Belt / lead screw | ~$150-300 | `pymodbus` (ModbusTCP) — no SDK |
| Bosch Rexroth aluminum | 10+ kg | 3 m+ | Rack-and-pinion | ~$300-600 | PLC integration only |

### Controller Options

| Controller | Interface | Python Package | Notes |
|---|---|---|---|
| OpenBuilds BlackBox (Grbl) | USB serial 115200 | `grbl-streamer` | Standard G-code |
| xPro V5 (FluidNC/ESP32) | USB + WiFi + WebSocket | `pyserial` / `websockets` | YAML config, REST + WebSocket API |
| ODrive | USB/CAN | `odrive` (PyPI v0.6.11) | Async Python, brushless servo |
| Moteus | CAN-FD/USB | `moteus` (PyPI v0.3.99) | Async Python, position/velocity/torque |
| Klipper `manual_stepper` | USB serial | `moonraker-api` (PyPI) | Reuse Klipper stack for single axis |

**Recommendation:** OpenBuilds C-Beam + FluidNC on ESP32. G-code + WebSocket +
Python via `grbl-streamer`, with community precedent for non-CNC linear motion.

## Workspace Advantages

- Eliminates arm bench footprint entirely.
- Reach envelope shifts from hemisphere-above-table to downward-facing cone.
- Collision avoidance simplifies — arm approaches from above, not around
  obstacles at bench level.
- Rail axis extends reach beyond a single arm's work envelope.

## Software Impact

- **URDF:** Rotate base link 180 deg around Y-axis. DH parameters unchanged.
- **Gravity compensation:** Sign flip on virtual displacement direction. See
  phospho.ai gravity compensation guide for SO-100/101.
- **IK:** `lerobot-kinematics` (box2ai-robotics) provides IK for SO-100;
  gravity vector changes but joint geometry is identical.
- **ACT policies:** Do NOT transfer from tabletop to inverted — joint angle
  distributions and gravity dynamics differ. Requires new teleoperation
  demonstrations with arm inverted.
- **SafetyMonitor:** Existing `JOINT_LIMITS` in `safety.py` apply, but limits
  should be re-validated for inverted loading.
- **XZGantry interaction:** Ceiling rail may replace or complement the existing
  XZ gantry (ceiling = long axis, gantry = cross axis).

## Safety Considerations

- **Falling risk:** Primary hazard. Redundant mechanical fastening (bolts +
  safety cable). STS3215 servos have no brake — arm free-falls on power loss.
  Mitigate with spring-return or counterweight.
- **E-stop:** Must cut servo power AND engage mechanical brake or friction lock.
- **Vibration:** Belt-driven movement transmits vibration. Pause and settle
  after gantry moves before pipetting. Rubber isolator mount plate recommended.
- **Drip risk:** Inverted arm above open containers — any debris/lubricant
  falls into samples. Use enclosed cable routing and drip shields.

## Precedents

- **Yamaha YK-XGS** — purpose-built ceiling-mount SCARA (industrial).
- **UR cobots** — officially support floor, wall, and ceiling mounting with
  software installation angle parameter.
- **Yaskawa HC cobots** — inverted mounting with 180 deg mount angle setting.
- No documented SO-101/SO-100 inverted mounting found (this would be novel).

## Quick Refs

| Ref | URL |
|-----|-----|
| SO-101 docs (HuggingFace) | <https://huggingface.co/docs/lerobot/so101> |
| SO-ARM100 (TheRobotStudio) | <https://github.com/TheRobotStudio/SO-ARM100> |
| Gravity compensation (phospho.ai) | <https://docs.phospho.ai/learn/gravity-compensation> |
| lerobot-kinematics | <https://github.com/box2ai-robotics/lerobot-kinematics> |
| Inverted robots overview | <https://www.robots.com/blogs/topsy-turvy-invert-mounted-robots> |
| Yamaha YK-XGS ceiling SCARA | <https://global.yamaha-motor.com/business/robot/lineup/ykxg/hang_inverse/> |
| Yaskawa HC inverted arm | <https://knowledge.motoman.com/hc/en-us/articles/23505485971991-HC-Robots-Wall-Mounted-or-Inverted-Arm-Control> |
| OpenBuilds V-Slot gantry carts | <https://us.openbuilds.com/gantry-carts-kits/> |
| OpenBuilds Python serial thread | <https://builds.openbuilds.com/threads/python-serial-communication-with-blackbox.18451/> |
| FluidNC (ESP32 Grbl) | <https://github.com/bdring/FluidNC> |
| FluidNC WebSocket docs | <http://wiki.fluidnc.com/en/support/interface/websockets> |
| FluidNC Web API | <http://wiki.fluidnc.com/en/features/WebAPI> |
| grbl-streamer (PyPI) | <https://pypi.org/project/grbl-streamer/> |
| ODrive Python (PyPI) | <https://pypi.org/project/odrive/> |
| Moteus Python (PyPI) | <https://pypi.org/project/moteus/> |
| TMC2209-PY (PyPI) | <https://pypi.org/project/TMC2209-PY/> |
| Klipper manual_stepper config | <https://www.klipper3d.org/Config_Reference.html> |
| moonraker-api (PyPI) | <https://pypi.org/project/moonraker-api/> |
| igus drylin actuators | <https://www.igus.com/drylin-e/turnkey-linear-actuators> |
| igus Robot Control (iRC) | <https://www.igus.co.uk/info/robot-software> |
| ROS ceiling mounting discussion | <https://answers.ros.org/question/321902/mounting-robot-arm-from-ceiling/> |

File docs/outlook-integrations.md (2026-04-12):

---
title: "Outlook: ELN, LIMS & Protocol Tool Integration"
purpose: Feasibility study for integrating eLabFTW, SiLA 2, PyLabRobot, and other tools into the workflow
authority: Research (INFORMATIONAL — not requirements)
created: 2026-04-12
updated: 2026-04-12
---

# Outlook: ELN, LIMS & Protocol Tool Integration

## Concept

The project handles the physical automation layer (arms, pipette, tool changer,
Bento, gantry, camera). The missing layers are experiment recording, reagent
inventory, protocol standardization, and device interoperability. This document
surveys tools that fill those gaps and evaluates their programmability.

## Architecture Vision

```text
+---------------------------------------------+
|  ELN (eLabFTW / openBIS)                    |  <- experiment records, inventory
+---------------------------------------------+
|  Protocol Layer (SiLA 2 / Autoprotocol)     |  <- machine-readable protocols
+---------------------------------------------+
|  Orchestrator (workflow.py)                  |  <- YOU ARE HERE
+---------------------------------------------+
|  Device Layer (arms, pipette, gantry, etc.) |  <- YOU ARE HERE
+---------------------------------------------+
|  Dashboard (server.py)                       |  <- YOU ARE HERE
+---------------------------------------------+
```

## ELN / LIMS Tools

### eLabFTW — Recommended

Open-source (GPLv3), self-hosted via Docker, REST API v2 with full OpenAPI spec.

| Aspect | Detail |
|---|---|
| Architecture | PHP/MySQL, Docker Compose deployment |
| API | REST v2, OpenAPI/Swagger, API key auth, no documented rate limits |
| Python clients | **elAPI** (Uni Heidelberg, v2.4.10, `uv add elapi`) — best DX. **elabapi-python** (official, v5.5.0, auto-generated from OpenAPI) — thin but current |
| Extensibility | No plugin system, no webhooks. Customization via Docker env vars and API |
| Docs | Good (docs.elabftw.net, Swagger UI for API exploration) |
| GitHub | 1,307 stars, 291 forks, actively maintained |

**Integration pattern with this project:**
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

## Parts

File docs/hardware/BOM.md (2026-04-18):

---
title: Bill of Materials
purpose: Hardware shopping list with first-party vendor links and cost estimates
authority: Hardware (AUTHORITY)
created: 2026-03-27
updated: 2026-04-11
validated_links: 2026-03-27
---

# Bill of Materials

Hardware shopping list for the so101-biolab-automation prototype.

Prices are estimates as of March 2026. Servo specs and gear ratios per
[SO-ARM100 README](https://github.com/TheRobotStudio/SO-ARM100#parts-for-two-arms-follower-and-leader-setup).
Leader arm motor mapping per
[LeRobot SO-101 docs](https://huggingface.co/docs/lerobot/so101#step-by-step-assembly-instructions).

## Arms (2x follower + 1x leader)

| Part | Qty | ~Cost | Source |
|---|-----|---|---|
| STS3215 Servo 7.4V, 1/345 gear (C001) | 13 | $14 ea | [Feetech STS3215 (Alibaba)](https://www.alibaba.com/product-detail/Feetech-STS3215-30KG-Serial-Bus-Servo_1601097543776.html), [Seeed Studio](https://www.seeedstudio.com/STS3215-30KG-Serial-Servo-p-6340.html) |
| STS3215 Servo 7.4V, 1/191 gear (C044) | 2 | $14 ea | Same — leader joints 1, 3 ([gear ratio table](https://huggingface.co/docs/lerobot/so101#step-by-step-assembly-instructions)) |
| STS3215 Servo 7.4V, 1/147 gear (C046) | 3 | $14 ea | Same — leader joints 4, 5, 6 |
| Waveshare Serial Bus Servo Driver Board | 3 | $11 ea | [Waveshare wiki](https://www.waveshare.com/wiki/Bus_Servo_Adapter) |
| USB-C Cable | 3 | $4 ea | Generic |
| 5V 4A DC Power Supply (5.5x2.1mm) | 3 | $10 ea | Generic |
| Table Clamp | 6 | $3 ea | Generic |
| Screwdriver Set (Phillips #0, #1) | 1 | $6 | Generic |

**Or buy assembled kits** (per [SO-ARM100 vendor list](https://github.com/TheRobotStudio/SO-ARM100#kits)):

- [Seeed Studio](https://www.seeedstudio.com/so-arm100-Standard-Kit-p-6329.html) — international, 3D printed kits
- [PartaBot](https://www.partabot.com/) — US, assembled versions
- [WowRobo](https://www.wowrobo.com/) — international, assembled versions

## 3D Printed Parts

Print settings per [SO-ARM100 printing guide](https://github.com/TheRobotStudio/SO-ARM100#printing-the-parts):
PLA+, 0.4mm nozzle, 0.2mm layer, 15% infill, supports >45 degrees.

| Part | Source |
|---|---|
| Follower arm (all parts, single plate) | [SO-ARM100 STL (follower)](https://github.com/TheRobotStudio/SO-ARM100/tree/main/STL/SO101) |
| Leader arm (all parts, single plate) | [SO-ARM100 STL (leader)](https://github.com/TheRobotStudio/SO-ARM100/tree/main/STL/SO101) |

**Custom parts:**

| Part | Status | Source | Material | Notes |
|---|---|---|---|---|
| Pipette mount adapter | Designed | `cad/so101/pipette_mount.py` | PLA+ | dPette barrel clamp for SO-101 wrist |
| Tool dock (3-station) | Designed | `cad/so101/tool_dock.py` | PLA+ | Magnetic dock, ref: [Berkeley tool changer](https://goldberg.berkeley.edu/pubs/CASE2018-ron-tool-changer-submitted.pdf) |
| Tool cones (robot/pipette/gripper) | Designed | `cad/so101/tool_changer.py` | PLA+ | Passive tool changer cones |
| Compliant gripper tips | Designed | `cad/so101/gripper_tips.py` | TPU 95A | Ref: [silicone mold (Thingiverse)](https://www.thingiverse.com/thing:7152864), [fin-ray gripper (MakerWorld)](https://makerworld.com/en/models/2075813) |
| 96-well plate holder | Designed | `cad/labware/plate_holder.py` | PLA+ | SBS footprint alignment pins |
| Tip rack holder | Designed | `cad/labware/tip_rack_holder.py` | PLA+ | Holds standard pipette tip rack |
| dPette single cradle | Designed | `cad/dpette/dpette_cradle.py` | PLA+ | Rest cradle for AELAB dPette 7016 |
| dPette multi cradle | Designed | `cad/dpette/dpette_cradle.py` | PLA+ | Rest cradle for DLAB dPette+ 8-channel |
| Tip ejection post | Designed | `cad/dpette/tip_ejection_bar.py` | PLA+ | Fixed post — arm pushes ejector button onto post to pop tips |
| dPette handle (U-bracket mount) | Designed | `cad/dpette/dpette_handle.py` | PLA+ | Single-channel dPette mount for SO-101 (M5 horn → barrel clamp) |
| dPette cam arm | Designed | `cad/dpette/dpette_handle.py` | PLA+ | Straight radial arm on M6 horn — sweeps into ejector hook |
| dPette tip release station | Designed | `cad/dpette/dpette_tip_release.py` | PLA+ | L-bracket ejector + waste slot, universal single/multi-channel |
| dPette+ 8-ch mount (split-bore clamp) | Designed | `cad/dpette/dpette_multi_handle.py` | PLA+ | Ø32mm split-bore clamp replacing SO-101 bottom jaw — **derived from 1:1 mm Revopoint scan** (`hardware/scans/dpette/`) |
| dPette+ ejector lever | Designed | `cad/dpette/dpette_multi_handle.py` | PLA+ | M6-horn-mounted lever replacing SO-101 top jaw — ~175N @ 20mm arm |
| Fridge hook end-effector | Designed (deferred) | `cad/so101/fridge_hook.py` | PLA+ | Hook for fridge door handle |
| XZ gantry frame | Designed (deferred) | `cad/deferred/xz_gantry_frame.py` | PLA+ | XZ gantry structural frame |
| XZ carriage pipette dock | Designed (deferred) | `cad/deferred/xz_carriage.py` | PLA+ | XZ gantry carriage with pipette dock |

## 3D Printer (for custom parts)

| Part | ~Cost | Source | Notes |
|---|---|---|---|
| [Original Prusa MK4](https://www.prusa3d.com/product/original-prusa-mk4s-3d-printer/) | ~$800 kit / ~$1,100 assembled | Prusa Research | Nextruder + input shaper. PrusaLink HTTP API + MK4 slicer profiles bundled at `src/hardware/slicer/profiles/prusa_mk4_*.ini`. See [prusa-mk4-ops.md](prusa-mk4-ops.md) for the API reference and upload / print curl examples. |
| PLA+ filament (1 kg) | $20–25 | [Prusament PLA](https://www.prusa3d.com/product/prusament-pla-prusa-galaxy-black-1kg-nfc/) or generic | Default material for functional parts |
| TPU 95A filament (0.5 kg) | $25 | Generic | Only for `gripper_tips_tpu.stl` |
| 0.4mm nozzle | — | included with MK4 | Default profile targets 0.4mm |

**Alternative printers** supported by the slicer pipeline: any PrusaSlicer-compatible printer. Pipeline is slicer-agnostic — swap profiles to target a different machine without code changes. Bambu Lab printers remain the target for the future camera + VLM agent-loop step (see [roadmap.md](../roadmap.md)).

## 3D Scanner (for scan-informed CAD, optional)

| Part | ~Cost | Source | Notes |
|---|---|---|---|
| [Revopoint MINI 2](https://www.revopoint3d.com/products/industry-3d-scanner-mini) or similar | $450–900 | Revopoint | Structured-light scanner for capturing physical parts as reference geometry. Output PLY/STL at 1:1 mm. See `hardware/scans/dpette/` for the dPette+ handle scan that drove the `dpette_multi_handle` redesign. |

Scanner is **optional** — most parts are purely parametric. Scan-informed design is useful for fitting custom mounts to off-the-shelf hardware with complex curved geometry (pipettes, grips, handles).

## Cameras

| Part | Qty | ~Cost | Source |
|---|-----|---|---|
| 32x32mm UVC camera module (wrist) | 2 | $15 ea | Per [SO-ARM100 wrist camera options](https://github.com/TheRobotStudio/SO-ARM100#5-wristmount-cameras) |
| USB webcam 1080p (overhead) | 1 | $25 | Per [SO-ARM100 overhead mount](https://github.com/TheRobotStudio/SO-ARM100#2-overhead-camera-mount) |

## Commercial Electronic Pipettes (Primary)

| Part | Qty | ~Cost | Source | Notes |
|---|-----|---|---|---|
| AELAB dPette 7016 (single-channel, 0.5–10,000 µL) | 1 | ~$200 | AELAB | USB port — protocol TBD (see `ElectronicPipette` backend) |
| DLAB dPette+ (8-channel, 0.5–300 µL) | 1 | ~$600 | DLAB | USB port — protocol TBD (same approach) |
| Pipette tips (compatible with dPette) | 1 box ea | $15 ea | Lab supply | |

## Digital Pipette (DIY Alternative)

Based on [digital-pipette-v2](https://github.com/ac-rad/digital-pipette-v2)
([paper: RSC Digital Discovery 2026](https://pubs.rsc.org/en/content/articlehtml/2026/dd/d5dd00336a)).

| Part | Qty | ~Cost | Source |
|---|-----|---|---|
| 1mL syringe (Luer slip) | 5 | $5 | Lab supply |
| Linear actuator L16-50-63-6-R (5cm stroke) | 1 | $70 | [Actuonix (manufacturer)](https://www.actuonix.com/l16-50-63-6-r) |
| Arduino Nano | 1 | $5 | [Arduino store](https://store.arduino.cc/products/arduino-nano) |
| 3D-printed pipette body | 1 | — | [STL + code](https://github.com/ac-rad/digital-pipette-v2) |
| Pipette tips (1-200 uL) | 1 box | $15 | Lab supply |

## XZ Gantry (Dedicated Pipetting Arm)

Simpler alternative to SO-101 for repetitive pipetting at fixed positions.

| Part | Qty | ~Cost | Source |
|---|-----|---|---|
| MGN12 linear rail (200mm) | 2 | $15 ea | AliExpress / Amazon |
| NEMA 17 stepper motor | 2 | $10 ea | Generic |
| GT2 timing belt + pulleys | 1 set | $8 | Generic |
| Pololu Maestro 6-ch USB servo controller | 1 | $18 | [Pololu](https://www.pololu.com/product/1350) |
| *Alternative:* Raspberry Pi Pico W | 1 | $6 | [raspberrypi.com](https://www.raspberrypi.com/products/raspberry-pi-pico/) |
| 3D-printed frame + carriage | 1 | ~$5 | Custom STL (see hardware parts issue) |

Estimated total: ~$60-80

## PCR Equipment

| Part | Qty | ~Cost | Source | Notes |
|---|-----|---|---|---|
| [Bento Lab](https://www.bento.bio/) (portable PCR) | 1 | ~$1,500 | Bento Bioworks | Centrifuge + thermocycler + gel electrophoresis. USB control TBD. |

## Edge Compute

| Option | Cost | Source | Notes |
|---|---|---|---|
| Raspberry Pi 5 (8GB) | $80 | [raspberrypi.com](https://www.raspberrypi.com/products/raspberry-pi-5/) | LeRobot inference, no GPU training |
| Jetson Orin Nano (8GB) | $250 | [nvidia.com](https://www.nvidia.com/en-us/autonomous-machines/embedded-systems/jetson-orin/) | GPU for on-device ACT policy training |
| microSD 64GB+ | $10 | Generic | |
| USB hub (4+ ports) | $15 | Generic | 3 motor boards + cameras |

LeRobot supports both platforms per [LeRobot docs](https://huggingface.co/docs/lerobot/index).
Seeed Studio offers [reComputer Jetson + SO-101 kits](https://wiki.seeedstudio.com/lerobot_so100m/).

## Lab Consumables

| Part | Qty | ~Cost | Notes |
|---|-----|---|---|
| 96-well microplate (SBS, flat bottom) | 5 | $20 | [SBS/ANSI standard](https://en.wikipedia.org/wiki/Microplate#Standards): 127.76 x 85.48 mm, 9mm spacing |
| Reagent trough (25mL, SBS footprint) | 2 | $10 | Lab supply |
| Colored water / food dye | — | $5 | For demo visualization |

## Cost Summary

| Config | Estimated Cost |
|---|---|
| Minimum (1 follower + 1 leader, RPi, no pipette) | ~$350 |
| Full SO-101 (2 followers + 1 leader, RPi, DIY pipette, cameras) | ~$650 |
| Full SO-101 + Jetson (GPU training on-device) | ~$820 |
| Full SO-101 + Prusa MK4 (for on-site custom part iteration) | ~$1,450 |
| XZ gantry only (dedicated pipetting, commercial pipettes) | ~$860 (gantry ~$60 + dPette 7016 ~$200 + dPette+ ~$600) |
| Full system (SO-101 + XZ gantry + Bento Lab + MK4) | ~$4,000+ |
| Full system + Revopoint scanner (scan-informed CAD workflow) | ~$4,500+ |

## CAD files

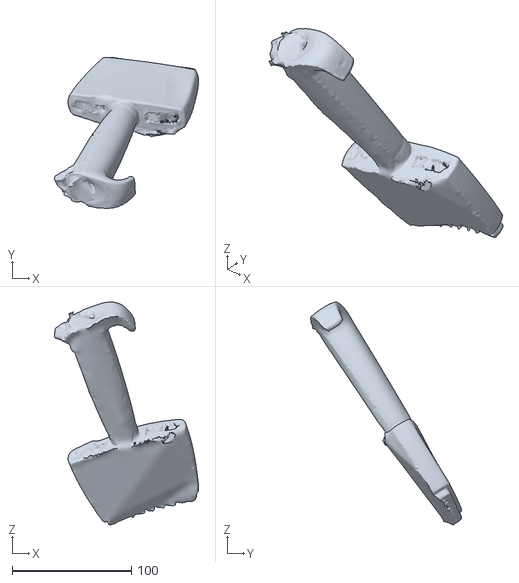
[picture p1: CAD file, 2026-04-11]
hardware/scans/dpette/0410_02_mesh.ply
121.2 x 127.0 x 187.1

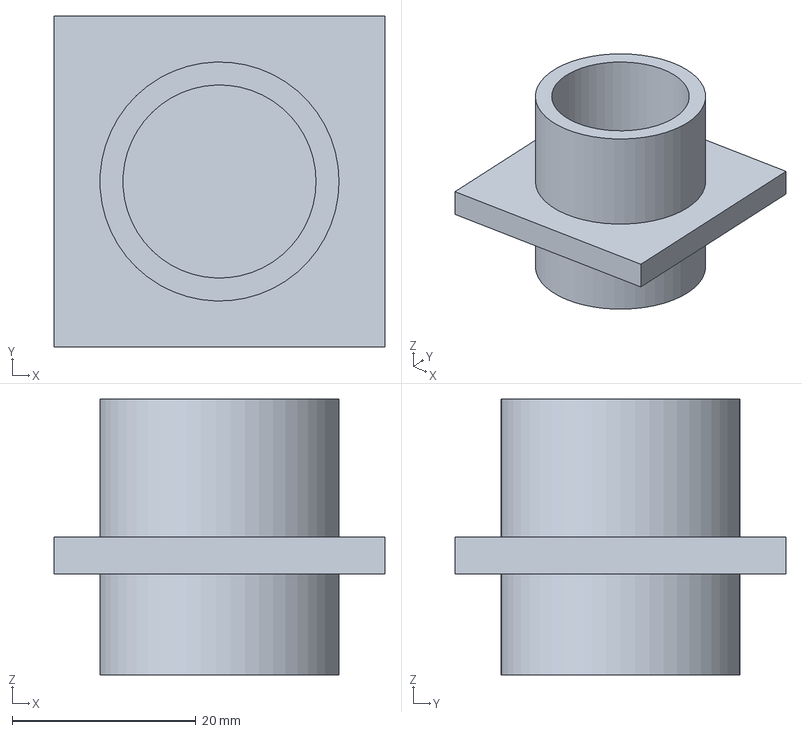
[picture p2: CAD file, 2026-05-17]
hardware/step/dpette/dpette_single_cradle.step
36.0 x 36.0 x 30.0 mm

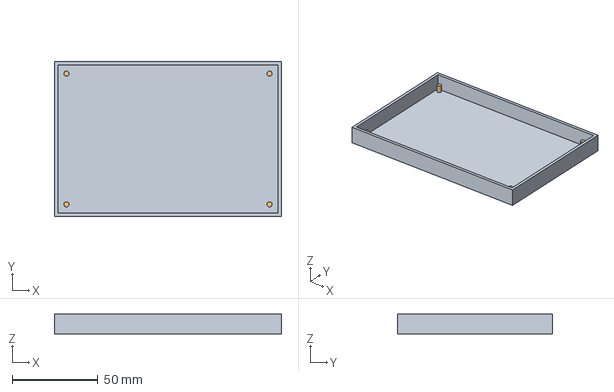
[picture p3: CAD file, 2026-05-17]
hardware/step/labware/96well_plate_holder.step
132.8 x 90.5 x 11.6 mm

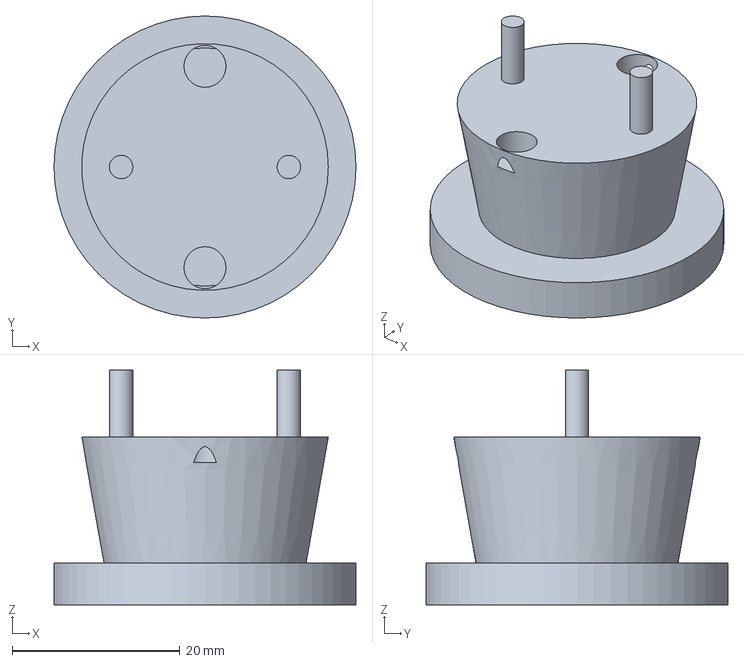
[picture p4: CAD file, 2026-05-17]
hardware/step/so101/tool_cone_pipette.step
36.0 x 36.0 x 28.0 mm

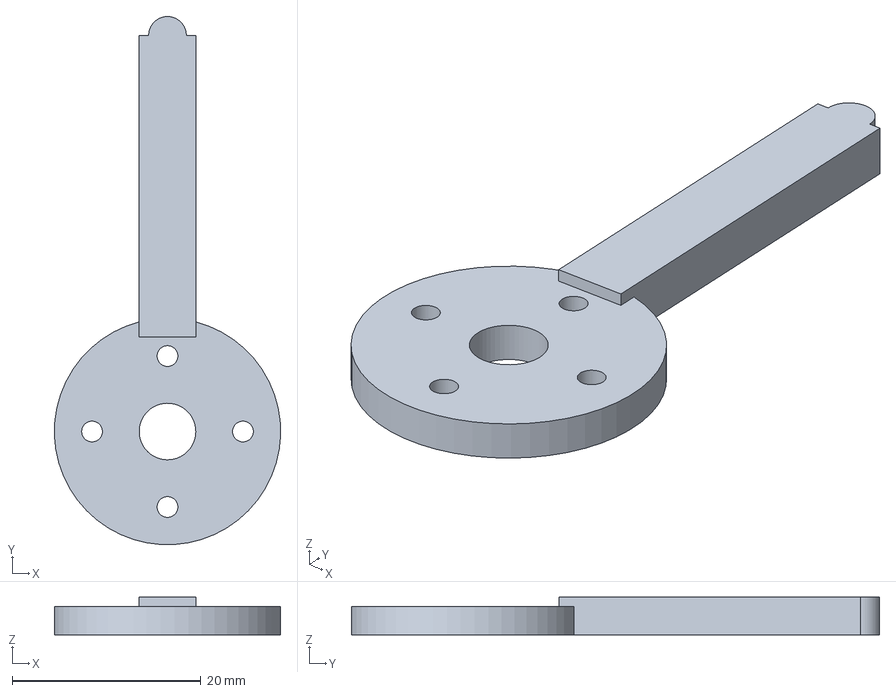
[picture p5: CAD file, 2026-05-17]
hardware/step/dpette/dpette_cam_arm.step
24.0 x 56.0 x 4.00 mm

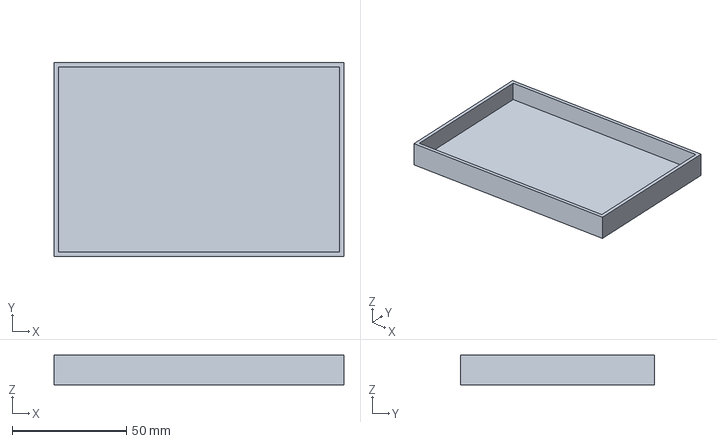
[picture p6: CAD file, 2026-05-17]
hardware/step/labware/tip_rack_holder.step
127.0 x 85.0 x 13.0 mm

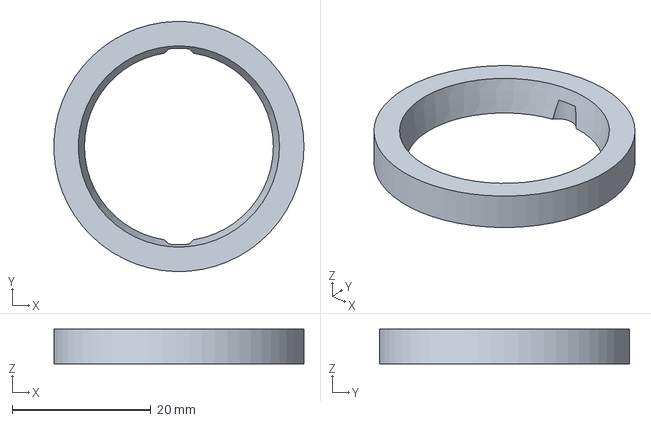
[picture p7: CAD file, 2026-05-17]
hardware/step/so101/tool_cone_robot.step
36.0 x 36.0 x 5.00 mm

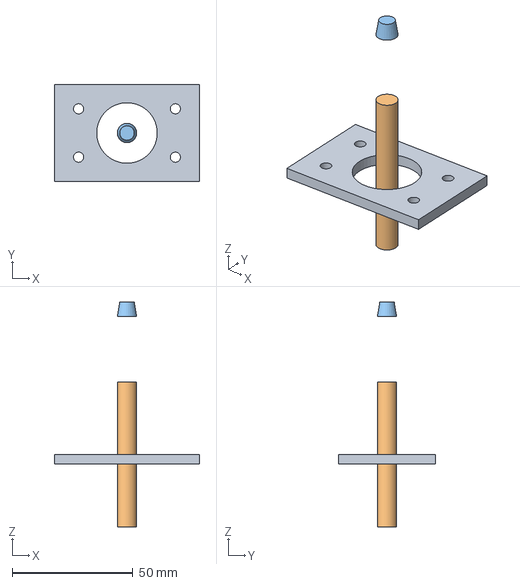
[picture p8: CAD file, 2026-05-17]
hardware/step/dpette/tip_ejection_bar.step
60.0 x 40.0 x 93.0 mm

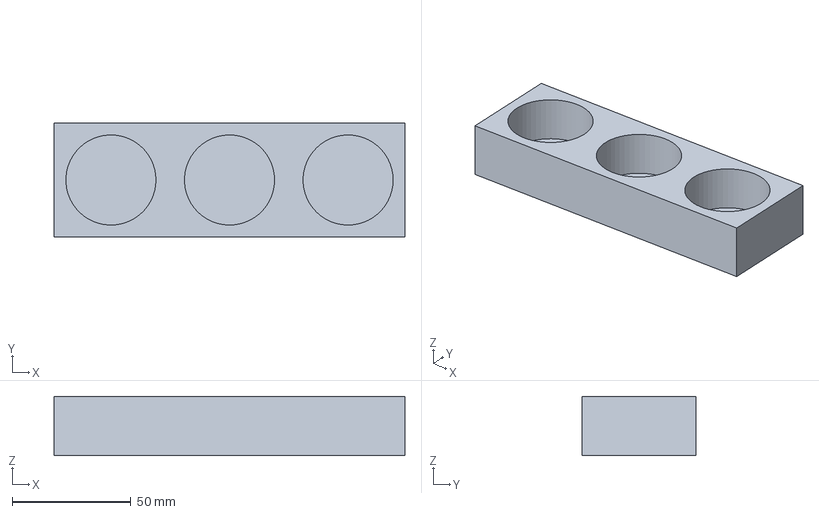
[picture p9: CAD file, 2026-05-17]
hardware/step/so101/tool_dock_3station.step
148.0 x 48.0 x 25.0 mm

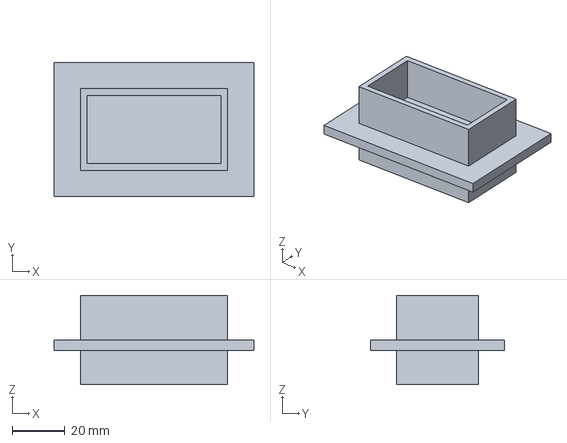
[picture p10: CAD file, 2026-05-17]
hardware/step/dpette/dpette_multi_cradle.step
76.0 x 51.0 x 34.0 mm

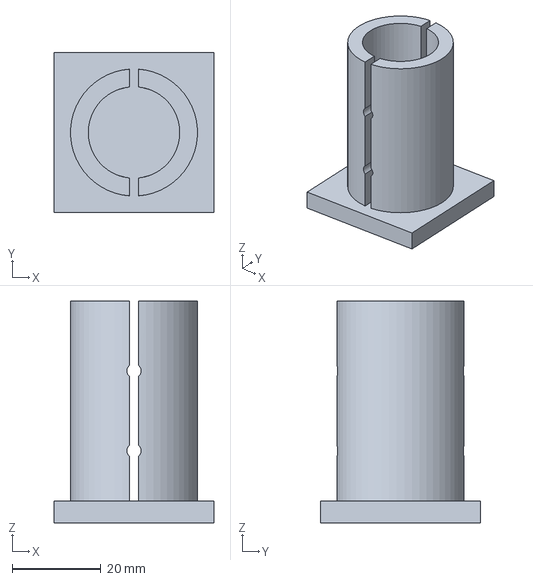
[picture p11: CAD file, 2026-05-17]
hardware/step/so101/pipette_mount_so101.step
36.0 x 36.0 x 50.0 mm

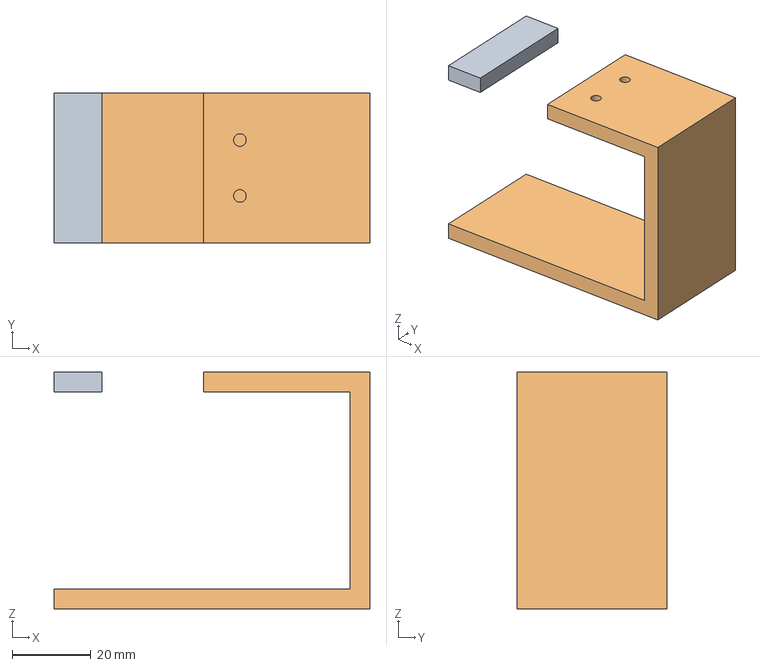
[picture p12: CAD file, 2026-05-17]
hardware/step/dpette/dpette_handle.step
80.0 x 38.0 x 60.0 mm

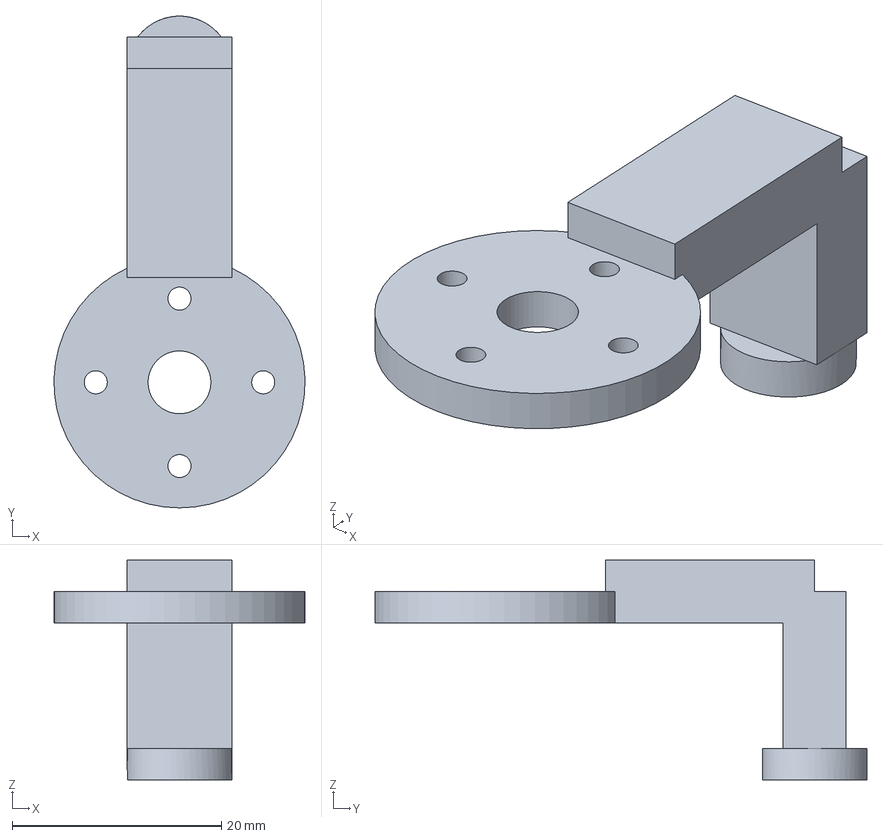
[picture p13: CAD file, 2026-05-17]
hardware/step/dpette/dpette_ejector_lever.step
24.0 x 47.0 x 21.0 mm

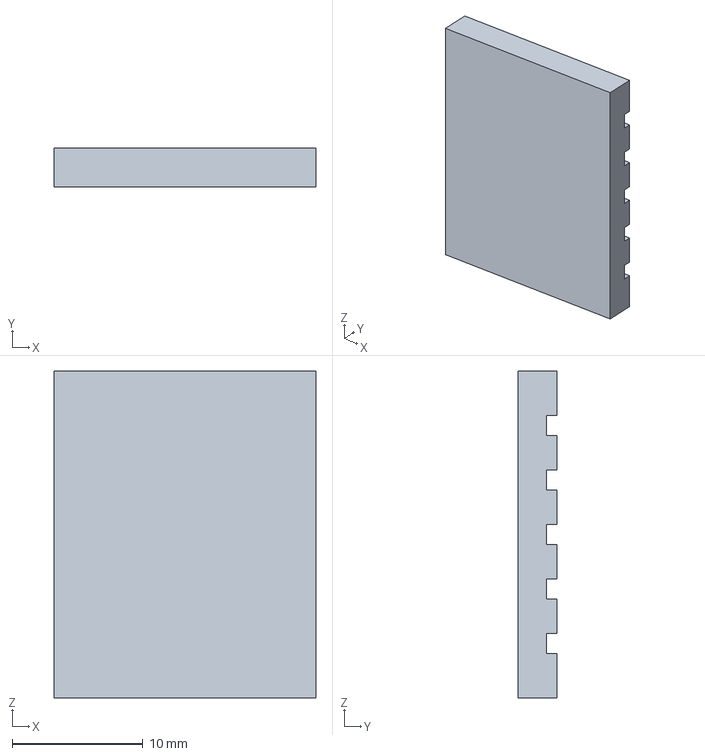
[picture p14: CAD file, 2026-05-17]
hardware/step/so101/gripper_tips_tpu.step
20.0 x 3.00 x 25.0 mm

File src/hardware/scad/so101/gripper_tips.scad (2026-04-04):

// Gripper fingertip attachments — TPU 95A with grip ridges
// Port of hardware/cad/gripper_tips.py
// Regenerate: openscad -o hardware/stl/gripper_tips_tpu.stl hardware/scad/gripper_tips.scad

// Parameters (mm)
FINGER_WIDTH  = 20.0;
TIP_THICKNESS = 3.0;
TIP_LENGTH    = 25.0;
RIDGE_COUNT   = 5;
RIDGE_DEPTH   = 0.8;
RIDGE_WIDTH   = 1.5;

// Tip base with grip ridges cut out
difference() {
    cube([FINGER_WIDTH, TIP_THICKNESS, TIP_LENGTH], center = true);

    // Cut ridges along the grip surface
    for (i = [0 : RIDGE_COUNT - 1]) {
        z_pos = -TIP_LENGTH / 2 + TIP_LENGTH / (RIDGE_COUNT + 1) * (i + 1);
        translate([0, TIP_THICKNESS / 2 - RIDGE_DEPTH / 2 + 0.5, z_pos])
            cube([FINGER_WIDTH + 1, RIDGE_DEPTH, RIDGE_WIDTH], center = true);
    }
}

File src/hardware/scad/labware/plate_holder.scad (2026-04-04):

// 96-well microplate holder — SBS/ANSI standard with alignment pins
// Port of hardware/cad/plate_holder.py
// Regenerate: openscad -o hardware/stl/96well_plate_holder.stl hardware/scad/plate_holder.scad

// Parameters (mm)
PLATE_LENGTH    = 127.76;  // SBS standard
PLATE_WIDTH     = 85.48;   // SBS standard
PLATE_HEIGHT    = 14.35;
WALL_THICKNESS  = 2.0;
BASE_THICKNESS  = 3.0;
HOLDER_CLEARANCE = 0.5;
PIN_DIAMETER    = 3.0;
PIN_HEIGHT      = 5.0;
PIN_INSET       = 5.0;

// Derived
INNER_L    = PLATE_LENGTH + HOLDER_CLEARANCE * 2;  // 128.76
INNER_W    = PLATE_WIDTH  + HOLDER_CLEARANCE * 2;  // 86.48
OUTER_L    = INNER_L + WALL_THICKNESS * 2;          // 132.76
OUTER_W    = INNER_W + WALL_THICKNESS * 2;          // 90.48
WALL_HEIGHT = PLATE_HEIGHT * 0.6;                    // 8.61
FLOOR_DEPTH = 1.0;

union() {
    // Base plate with pocket (floor_depth = 1mm)
    difference() {
        translate([0, 0, BASE_THICKNESS / 2])
            cube([OUTER_L, OUTER_W, BASE_THICKNESS], center = true);
        // Pocket cut (leave 1mm floor)
        translate([0, 0, FLOOR_DEPTH + (BASE_THICKNESS - FLOOR_DEPTH) / 2 + 0.01])
            cube([INNER_L, INNER_W, BASE_THICKNESS - FLOOR_DEPTH + 0.02], center = true);
    }

    // Walls
    translate([0, 0, BASE_THICKNESS + WALL_HEIGHT / 2])
        difference() {
            cube([OUTER_L, OUTER_W, WALL_HEIGHT], center = true);
            cube([INNER_L, INNER_W, WALL_HEIGHT + 1], center = true);
        }

    // 4 alignment pins at corners
    for (sx = [-1, 1])
        for (sy = [-1, 1])
            translate([
                sx * (INNER_L / 2 - PIN_INSET),
                sy * (INNER_W / 2 - PIN_INSET),
                BASE_THICKNESS + PIN_HEIGHT / 2
            ])
                cylinder(h = PIN_HEIGHT, d = PIN_DIAMETER, center = true, $fn = 24);
}

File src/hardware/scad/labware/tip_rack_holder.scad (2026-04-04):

// Tip rack holder — tray with walls for standard 96-tip rack
// Port of hardware/cad/tip_rack_holder.py
// Regenerate: openscad -o hardware/stl/tip_rack_holder.stl hardware/scad/tip_rack_holder.scad

// Parameters (mm)
RACK_LENGTH    = 122.0;
RACK_WIDTH     = 80.0;
WALL_THICKNESS = 2.0;
WALL_HEIGHT    = 10.0;
BASE_THICKNESS = 3.0;
CLEARANCE      = 0.5;

// Derived
INNER_L = RACK_LENGTH + CLEARANCE * 2;  // 123.0
INNER_W = RACK_WIDTH  + CLEARANCE * 2;  // 81.0
OUTER_L = INNER_L + WALL_THICKNESS * 2; // 127.0
OUTER_W = INNER_W + WALL_THICKNESS * 2; // 85.0

// Base plate
translate([0, 0, BASE_THICKNESS / 2])
    cube([OUTER_L, OUTER_W, BASE_THICKNESS], center = true);

// Walls (outer box minus inner box)
translate([0, 0, BASE_THICKNESS + WALL_HEIGHT / 2])
    difference() {
        cube([OUTER_L, OUTER_W, WALL_HEIGHT], center = true);
        cube([INNER_L, INNER_W, WALL_HEIGHT + 1], center = true);
    }

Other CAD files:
hardware/step/dpette/dpette_multi_handle.step
hardware/step/dpette/dpette_tip_release.step
src/hardware/scad/so101/fridge_hook.scad
hardware/stl/dpette/dpette_cam_arm.stl
hardware/stl/dpette/dpette_ejector_lever.stl
hardware/stl/dpette/dpette_handle.stl
hardware/stl/dpette/dpette_multi_cradle.stl
hardware/stl/dpette/dpette_multi_handle.stl
hardware/stl/dpette/dpette_single_cradle.stl
hardware/stl/dpette/dpette_tip_release.stl
hardware/stl/dpette/tip_ejection_bar.stl
hardware/stl/labware/96well_plate_holder.stl
hardware/stl/labware/tip_rack_holder.stl
hardware/stl/so101/gripper_tips_tpu.stl
hardware/stl/so101/pipette_mount_so101.stl
hardware/stl/so101/tool_cone_gripper.stl
hardware/stl/so101/tool_cone_pipette.stl
hardware/stl/so101/tool_cone_robot.stl
hardware/stl/so101/tool_dock_3station.stl
src/hardware/scad/so101/pipette_mount.scad
src/hardware/scad/so101/tool_changer.scad
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

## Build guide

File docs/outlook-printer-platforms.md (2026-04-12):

---
title: "Outlook: 3D Printers & CNC as Pipetting Platforms"
purpose: Feasibility study for repurposing used 3D printers and CNC machines as Cartesian liquid handlers
authority: Research (INFORMATIONAL — not requirements)
created: 2026-04-12
updated: 2026-04-12
---

# Outlook: 3D Printers & CNC as Pipetting Platforms

## Concept

Repurpose used/older 3D printers as Cartesian liquid-handling platforms.
Their existing 3-axis motion systems achieve sufficient accuracy for well-plate
work at a fraction of the cost of commercial liquid handlers. This complements
(not replaces) the SO-101 arms — arms handle dexterous tasks (tool changing,
Bento lid, complex manipulation), while a printer handles high-throughput
Cartesian pipetting (serial dilutions, plate-to-plate transfers).

## Existing Conversion Projects

### Actively Maintained (Code Public, Python API)

| Project | Base Platform | Python API | PyPI | Stars | License | Docs |
|---|---|---|---|---|---|---|
| Science Jubilee | Jubilee (CoreXY, Duet3D) | `Machine` class, Jupyter-native | `science-jubilee` v0.3.2 | 40 | MIT | Good (ReadTheDocs) |
| PyLabRobot | Hardware-agnostic | Pluggable backends | `pylabrobot` v0.2.1 | 426 | MIT | Good |
| Opentrons OT-2 | Custom (ex-3D printer) | Protocol API | `opentrons` v9.0.0 | 498 | Apache-2.0 | Excellent |
| PipetBot-A8 | Anet A8 (Marlin) | `pyotronext` (serial G-code) | No | — | Unknown | Good (dedicated site) |

### Paper-Only (No Public Repo)

| Project | Cost | Key Result | Code |
|---|---|---|---|
| PALH (Brown, 2024) | ~$400 | Validated qPCR, DNA extraction | No repo |
| MULA | ~700 EUR | <0.3% pipetting error, Hamilton syringe | Partial (Mendeley, CC BY-NC 3.0) |
| BioCloneBot | ~$400 | Ender 3 Pro conversion | GitHub (2 stars, C# only, dormant) |
| FINDUS | <$400 | Fully 3D-printed, <0.3% error | No repo |
| OTTO | ~$1,500 | OpenBuilds linear rails | No repo |
| PHIL | — | Miniature, fits on microscope stage | No repo |

## Printer Comparison

| Printer | Build Volume (mm) | Motion | Bed Moves? | Firmware | Used Price | 384-Well? |
|---|---|---|---|---|---|---|
| **Voron 2.4** | 250-350 cubed | **CoreXY** | **No (Z only)** | **Klipper** | $500-800 (kit) | **Yes** |
| Sovol SV03 | 350x350x400 | Cartesian | Yes (Y) | Marlin | $80-140 | Marginal |
| Anycubic i3 Mega | 210x210x205 | Cartesian | Yes (Y) | Marlin | $60-120 | No |
| Geeetech A30 | 320x320x420 | Cartesian | Yes (Y) | Marlin | $80-150 | No |
| Qidi X-Max | 300x250x300 | Cartesian | Yes (Y) | Marlin fork | $150-250 | Marginal |

**Critical distinction:** Bed-slingers move the bed in Y — moving liquid-filled
wells risks spillage and positional error. The Voron 2.4 keeps the bed
stationary in XY, which is essential for plate work.

### Reflashability

All six printers can be reflashed with open firmware. All expose USB serial
G-code (115200 baud). Qidi X-Max has a locked bootloader on some revisions
(community workarounds exist).

## Firmware Ecosystems

### Klipper + Moonraker (Voron 2.4)

- Python host (`klippy`) on Raspberry Pi, thin C firmware on MCU.
- **Custom Python plugins:** `klippy/extras/` directory (~134 modules).
- **G-code macros:** `[gcode_macro]` with Jinja2 templates and variables.
  Define `ASPIRATE`, `DISPENSE`, `MOVE_TO_WELL` as macros.
- **Moonraker API:** REST + WebSocket. `POST /api/printer/command` (G-code),
  `GET /api/printer/objects/query` (status). Real-time subscriptions.
- **Python client:** `moonraker-api` on PyPI (v2.0.6) — async WebSocket.
- **Docs:** Excellent (config reference, API docs at moonraker.readthedocs.io).

### Marlin + OctoPrint (Budget Printers)

- **Serial G-code:** 115200 baud, USB-serial via CH340/FTDI.
- **Python serial control:** `printrun.printcore` (PyPI, 2.6k stars).
- **OctoPrint REST API:** `/api/printer/command`, `/api/printer` (status).
  `octorest` Python client on PyPI.
- **Custom G-code:** Requires C++ source mod and recompile (not pluggable).
- **Docs:** Good (OctoPrint API docs excellent, Marlin is config-focused).

### Duet3D / RepRapFirmware (Science Jubilee)

- **HTTP API:** `POST /machine/code` (SBC) or `GET /rr_gcode` (standalone).
- **Object model:** `GET /machine/status` for full printer state.
- **Docs:** Good. Simpler than Moonraker for direct G-code but fewer
  subscription features.

## Conversion Approach

1. **Tool head:** Replace hotend with syringe pump or electronic pipette mount.
   Extruder stepper (E-axis) drives the plunger. 3D-printed adapters suffice.
2. **Bed:** Replace with plate holder (3D-printed or machined). Science Jubilee
   uses a 6-plate deck matching SBS/ANSI footprint (128x86 mm).
3. **Firmware:** Repurpose E-axis G-code (`G1 E` commands) for aspirate/dispense.
   Custom macros map volume to stepper steps.
4. **Calibration:** Home XY to plate corner fiducials; Z-probe to plate surface.
   Well offset tables from ANSI/SLAS 4-2004 standard.

## Accuracy Requirements

| Plate | Well Pitch | Well Diameter | Required XY Accuracy |
|---|---|---|---|
| 96-well | 9.0 mm | ~6.5 mm | +/-1.0 mm (comfortable) |
| 384-well | 4.5 mm | ~3.5 mm | +/-0.5 mm (tight) |

Typical 3D printer repeatability: ~300-500 um (96-well OK, 384-well marginal).
Voron 2.4 with CoreXY and linear rails: <100 um — meets 384-well comfortably.

## Cost Comparison

| Approach | Cost | Plate Support |
|---|---|---|
| Used printer conversion (Ender 3, Sovol) | $325-700 | 96-well |
| Voron 2.4 build + conversion | $800-1,500 | 96 + 384-well |
| Science Jubilee (Filastruder kit) | ~$1,500-2,000 | 96 + 384 + tool changing |
| OpenBuilds custom (OTTO-style) | ~$1,500 | 96 + 384-well |
| Opentrons OT-2 | $6,000-10,000 | 96 + 384-well |
| Hamilton STAR/Vantage | $100,000+ | All formats |

## CNC Alternatives

| Platform | Frame | Cost | Rigidity | Suitability |
|---|---|---|---|---|
| PrintNC | Steel tube | $800-1,200 | Excellent | Overkill — designed for milling forces |
| MPCNC | Conduit/printed | $300-500 | Low-Medium | Large community, less precise |
| Workbee | Aluminum extrusion | $600-1,000 | Good | Clean motion, good middle ground |

Trade-off: CNC frames are more rigid but lack ready-made electronics, firmware
ecosystem, and extruder stepper for pipette actuation.

## Integration with This Project

- **`PipetteConfig` / `ElectronicPipetteConfig`** models already define pipette
  parameters — same pipette, just mounted on a printer carriage.
- **`PlateLayout`** model (well positions, pitch, origin offsets) maps directly
  to G-code well coordinates — the YAML config is already there.
- **Software layer:** Replace arm IK with G-code generation. PyLabRobot
  provides a hardware-agnostic Python API that could sit alongside `workflow.py`.
- **Complementary roles:** Arms handle dexterous tasks. Printer handles
  high-throughput Cartesian pipetting.

## Voron 2.4 as Standout Candidate

- Stationary bed — no liquid sloshing.
- CoreXY rigidity — aluminum extrusion + linear rails, <1% dimensional error.
- Klipper firmware — Python-based, trivial to add custom macros.
- Quad gantry leveling — automatic bed tramming for consistent Z.
- No existing Voron lab automation project found — this would be novel.

## Quick Refs

| Ref | URL |
|-----|-----|
| Science Jubilee (GitHub) | <https://github.com/machineagency/science-jubilee> |
| PyLabRobot (GitHub) | <https://github.com/PyLabRobot/pylabrobot> |
| PyLabRobot docs | <https://docs.pylabrobot.org/> |
| Opentrons (GitHub) | <https://github.com/Opentrons/opentrons> |
| Opentrons API docs | <https://docs.opentrons.com/> |
| PipetBot-A8 | <https://derandere.gitlab.io/pipetbot-a8/> |
| PALH paper (ScienceDirect) | <https://www.sciencedirect.com/science/article/pii/S2472630324001213> |
| BioCloneBot (HardwareX) | <https://www.hardware-x.com/article/S2468-0672(24)00010-5/fulltext> |
| ACS liquid handler paper | <https://pubs.acs.org/doi/10.1021/acs.jchemed.3c00855> |
| MULA (Printables) | <https://www.printables.com/model/1019242-mula-a-diy-3d-printed-pipetting-robot-enabling-acc> |
| FINDUS (SLAS) | <https://journals.sagepub.com/doi/10.1177/2472630319877374> |
| OTTO (Nature Sci. Reports) | <https://www.nature.com/articles/s41598-020-70465-5> |
| PHIL (Nature Comms) | <https://www.nature.com/articles/s41467-022-30643-7> |
| Digital Pipette v2 (ac-rad) | <https://github.com/ac-rad/digital-pipette-v2> |
| Voron Design | <https://vorondesign.com/voron2.4> |
| Voron 2.4 review (3DPI) | <https://3dprintingindustry.com/news/review-ldo-voron-2-4-300-a-premium-high-speed-diy-3d-printer-236079/> |
| Sovol refurbished printers | <https://www.sovol3d.com/products/sovol-used-3d-printer> |
| Anycubic i3 Mega CNC mod | <https://www.printables.com/model/35905-anycubic-i3-mega-cnc-mod> |
| Klipper config reference | <https://www.klipper3d.org/Config_Reference.html> |
| Moonraker API docs | <https://moonraker.readthedocs.io/> |
| moonraker-api (PyPI) | <https://pypi.org/project/moonraker-api/> |
| printrun (PyPI) | <https://pypi.org/project/printrun/> |
| OctoPrint REST API | <https://docs.octoprint.org/en/master/api/> |
| ANSI/SLAS 4-2004 well positions | <https://www.slas.org/SLAS/assets/File/public/standards/ANSI_SLAS_4-2004_WellPositions.pdf> |
| PrintNC (GitHub) | <https://github.com/threedesigns/printNC> |
| r/Sovol (Reddit) | <https://www.reddit.com/r/Sovol/> |

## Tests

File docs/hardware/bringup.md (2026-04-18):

# SO-101 Hardware Bringup Guide

Step-by-step procedure for bringing up the SO-101 dual-arm system.
Tested on Fedora 43, Python 3.12, lerobot 0.4.4.

> **Variant:** For a simplified 2-axis pipetting setup (shoulder_pan +
> shoulder_lift only, fixed electronic pipette mount), see
> [two-dof-pipette.md](two-dof-pipette.md).

## Prerequisites

- SO-101 arms assembled (2 followers + 1 leader), STS3215 servos, Waveshare serial bus servo driver boards
- USB-C cables connecting each Waveshare board to the PC
- 5V 4A power supplies connected and powered on
- `uv sync --group lerobot` completed (installs lerobot[feetech])

## 1. Serial Port Permissions

The Waveshare boards register as `/dev/ttyACM*` devices owned by the `dialout` group.

### Add user to dialout group

```bash
sudo usermod -aG dialout $USER
```

Requires **full re-login** to take effect (not just a new terminal).
`newgrp dialout` only affects the current shell, not subprocesses like `uv run`.

### Per-session alternative (no reboot)

```bash
sudo chmod 666 /dev/ttyACM0 /dev/ttyACM1 /dev/ttyACM2
```

Run this for **every connected arm** at the start of each session.

> **Note:** Resets on unplug/replug. For persistence, install a udev rule:
>
> ```bash
> make install_udev
> ```
>
> (writes `/etc/udev/rules.d/99-waveshare.rules` making Waveshare boards world-rw).

## 2. USB Enumeration

### Find ports

```bash
uv run lerobot-find-port   # or: make find_port
```

Interactive: lists ports, asks you to **unplug** the USB cable, press Enter, then detects which port disappeared.

### Verify with servo scan

```bash
uv run so101-scan-servos --port=/dev/ttyACM0   # or: make scan_servos PORT=/dev/ttyACM0
```

Expected output for one arm: 6 servos (IDs 1-6), model 777 (STS3215),
with firmware versions listed. A warning is emitted if firmware versions
differ — run `make patch_lerobot` in that case.

### Port assignments

| Arm | Default Port | Makefile Variable |
|-----|---|---|
| Leader | `/dev/ttyACM0` | `LEADER_PORT` |
| Follower A | `/dev/ttyACM1` | `FOLLOWER_A_PORT` |
| Follower B | `/dev/ttyACM2` | `FOLLOWER_B_PORT` |

> **Tip:** Port numbers depend on USB plug order, not physical slot. They shift
> on replug. Always verify with `ls /dev/ttyACM*` and the servo scan. If teleop
> has the wrong arm moving, swap the ports.

## 3. Firmware Version Check

LeRobot requires all servos on the same firmware version. If versions differ, `lerobot-calibrate` will fail:

```text
RuntimeError: Some Motors use different firmware versions:
{1: '3.10', 2: '3.9', 3: '3.10', 4: '3.10', 5: '3.10', 6: '3.10'}
```

### Option A: Flash mismatched servo (proper fix, requires Windows)

Firmware flashing uses a proprietary bootloader protocol — **no Linux tool exists**.
The `scservo_sdk` / `feetech-servo-sdk` only do register read/write, not firmware upload.

1. Get a Windows machine or VM with USB passthrough
2. Download FD software + firmware binary from <https://www.feetechrc.com/software>
3. **Disconnect all other servos** from the daisy chain — firmware flashing
   cannot address by ID, it uses a power-cycle bootloader handshake
4. Connect only the mismatched servo to the Waveshare board
5. Flash via FD tool
6. Reconnect all servos and verify

### Option B: Patch lerobot (prototyping only)

Mixed firmware causes **two** problems in lerobot 0.4.4:

1. `_assert_same_firmware()` raises `RuntimeError` blocking startup
2. `sync_read` fails with `[TxRxResult] Incorrect status packet!` — firmware
   3.9 returns a slightly different packet format that corrupts batch responses

Individual servo reads (`read2ByteTxRx`) work fine for all servos including 3.9.
The issue is only with sync (batch) reads across the shared bus.

The patch script fixes both:

```bash
uv run so101-patch-lerobot           # apply
uv run so101-patch-lerobot --revert  # restore
```

Or via Makefile: `make patch_lerobot` / `make patch_lerobot_revert`.

What it does:

- **Firmware check:** warns instead of raising `RuntimeError`
- **sync_read:** falls back to sequential individual reads when batch read fails
  (firmware 3.9 returns a different packet format that corrupts batch responses;
  individual reads work fine for all servos including 3.9)
- **Calibration clamp:** clamps range values to 0-4095 before writing to servo
  EPROM (glitchy reads via sign-magnitude decoding can produce negatives like -170,
  which the servo rejects)

This patches the **installed** lerobot package in-place (under `.venv/`).
The patch is overwritten by `uv sync` — re-run the script after reinstalling.

### Verifying patch compatibility after lerobot upgrade

The patches use exact-string replacement against lerobot source. When
bumping the lerobot version, run the compatibility guard tests to catch
upstream drift before it silently breaks calibration:

```bash
uv run --group lerobot pytest -m lerobot
```

If they fail, update the `ORIGINAL` / `PATCHED` constants in
`src/so101/cli/patch_lerobot.py` to match the new lerobot source.

> **Warning:** Sequential reads are slower than sync reads. This is acceptable
> for calibration and prototyping but may add latency during teleoperation.
> For production use, flash all servos to the same firmware version (Option A).

## 4. Pre-calibration Checklist

Before calibrating any arm:

1. **Permissions:** `sudo chmod 666 /dev/ttyACM*` (or udev rule)
2. **Patches:** `uv run so101-patch-lerobot` (if mixed firmware)
3. **Power:** 5V 4A supply connected and on for each Waveshare board
4. **Verify servos:** Run the servo scan script (section 2) to confirm 6 servos respond

## 5. Calibrate Leader Arm

```bash
uv run lerobot-calibrate \
  --teleop.type=so101_leader \
  --teleop.port=/dev/ttyACM0 \
  --teleop.id=leader
```

> **Important:** Leader arms use `--teleop.*` flags, not `--robot.*`.

### Calibration prompts

The calibration will ask you to move joints to the **middle of their range of motion**.
Use this as a reference for the neutral pose:

| Joint | Description | Middle position |
|---|---|---|
| 1 | Base rotation | Arm pointing straight forward |
| 2 | Shoulder | ~45°, halfway between up and horizontal |
| 3 | Elbow | ~90°, forearm halfway bent |
| 4 | Wrist pitch | Level / neutral |
| 5 | Wrist roll | Centered, no rotation |
| 6 | Gripper | Half open |

Put the arm in a relaxed, neutral pose — not at any extreme — then press Enter.

After the midpoint, you'll be asked to move each joint through its full range
(min to max). Move slowly and smoothly.

Calibration data is saved to `~/.cache/huggingface/lerobot/calibration/leader/`.

## 6. Calibrate Follower Arms

```bash
# Follower A
uv run lerobot-calibrate \
  --robot.type=so101_follower \
  --robot.port=/dev/ttyACM1 \
  --robot.id=arm_a

# Follower B
uv run lerobot-calibrate \
  --robot.type=so101_follower \
  --robot.port=/dev/ttyACM2 \
  --robot.id=arm_b
```

Or use the Makefile target (calibrates all three sequentially):

```bash
make calibrate_arms
```

## 7. Teleoperation Test (Grippers)

After calibration, test leader-follower teleoperation.

### Identify ports with multiple arms

`lerobot-find-port` fails with multiple boards plugged in:

```text
OSError: Could not detect the port. More than one port was found (['/dev/ttyACM1', '/dev/ttyACM0'])
```

Use `ls /dev/ttyACM*` instead. Port assignment depends on plug order, not
physical slot. If unsure which is leader vs follower, try one — if the arms
are swapped, flip the ports.

### Run teleoperation

```bash
sudo chmod 666 /dev/ttyACM0 /dev/ttyACM1
uv run lerobot-teleoperate \
  --robot.type=so101_follower \
  --robot.port=/dev/ttyACM1 \
  --teleop.type=so101_leader \
  --teleop.port=/dev/ttyACM0
```

Or via Makefile:

```bash
make start_teleop
```

Verify the follower arm mirrors the leader's movements.

## 8. Pipette Holder Swap

After grippers are working:

1. Print pipette holders (see [src/hardware/README.md](../../src/hardware/README.md) for parts list and print settings)
2. Mount holders on follower arm(s)
3. Re-calibrate if gripper-to-holder swap changes joint offsets
4. Test tool changer cycle: return gripper, pick up holder

## Troubleshooting

| Symptom | Cause | Fix |
|---|---|-----|
| `Permission denied: '/dev/ttyACM0'` | User not in `dialout` group | `sudo chmod 666 /dev/ttyACM*` or add to group + re-login |
| `newgrp dialout` doesn't help | Only affects current shell, not `uv run` subprocesses | Use `chmod 666` or udev rule instead |
| `lerobot-find-port` finds nothing | Didn't unplug cable during prompt | Unplug USB, press Enter, replug when told |
| `lerobot-find-port` multiple ports | Multiple boards plugged in | Use `ls /dev/ttyACM*` instead |
| `invalid choice: 'so101_leader'` for `--robot.type` | Leader uses `--teleop.type`, not `--robot.type` | Use `--teleop.type=so101_leader` |
| Firmware version mismatch | Servos on different FW versions | `uv run so101-patch-lerobot` or flash with FD |
| `Incorrect status packet!` on sync_read | FW 3.9 corrupts batch responses | Patch script adds sequential fallback |
| `Negative values are not allowed` | Glitchy read → negative via sign-magnitude decode | Patch script adds calibration clamp |
| `Input voltage error!` | Transient servo error during rapid reads | Patch script suppresses; check power if persistent |
| `Missing motor IDs` (all 6) | Power supply unplugged/off | Connect 5V 4A supply to Waveshare board |
| `Missing motor IDs` (some) | Servo overload/error lockout or loose cable | Power-cycle the 5V supply, reseat daisy-chain cables |
| Motor LED blinking during teleop | Servo error (overload/position) | Power-cycle; may indicate port swap (follower treated as leader) |
| Leader arm stuck / won't move by hand | Ports swapped — leader has torque on | Swap `--robot.port` and `--teleop.port` |
| `Mismatch between calibration values` | Patched clamp values differ from JSON | Press Enter to use saved calibration — this is expected |
| Teleop: `--robot.id` / `--teleop.id` missing | IDs default to None, can't find calibration | Always pass `--robot.id=arm_a --teleop.id=leader` |
| Same min and max during calibration | Joints not moved, or glitchy reads | Move each joint fully; ensure patch is applied |
| Port number shifted | USB re-enumeration on replug | `ls /dev/ttyACM*`; `sudo chmod 666` again |
| Gripper not following during teleop | Narrow calibration range on leader gripper | Re-calibrate with full gripper open/close range |
| Gripper servo LED blinking | Overload error — commanded to out-of-range position | Power-cycle 5V supply; check if gripper moves freely by hand when off |
| Servo overload after calibration mismatch | Leader/follower gripper ranges don't align | Re-calibrate both arms' grippers with matching full range |

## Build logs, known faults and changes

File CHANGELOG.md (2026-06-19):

# Changelog

Format based on [Keep a Changelog](https://keepachangelog.com/), [Semantic Versioning](https://semver.org/).

<!-- scriv-insert-here -->

## [Unreleased]

### Added

- **`FOXGLOVE_CAM_FLAGS` Makefile variable**: parallels `CAMERAS` for the foxglove path. Override with `make start_foxglove FOXGLOVE_CAM_FLAGS=""` to run headless. `foxglove_viz.py` already supports this (camera flags are optional in argparse; `_try_camera(None, ...)` returns early).
- **Live Visualization section** in README: collapsible `<details>` block with annotated Rerun.io screenshot (`assets/images/screenshot_rerun.io_so101.png`) showing joint time-series, observation streams, recording metadata, and blueprint panels. Notes `make start_foxglove` for the separate 3D + camera view.
- **`TODO:` comments** in Makefile above `start_teleop`, `record_episodes`, and `start_foxglove` marking the live-viz layer as partially validated (Rerun joint streams confirmed; Rerun camera path and Foxglove local+remote unverified on hardware).
- **Hardware bringup ergonomics for partial setups**:
  - Per-arm calibrate targets `calibrate_arm_a`, `calibrate_arm_b`, `calibrate_leader` — 2-arm setups (leader + one follower) can calibrate only what is connected (Makefile)
  - `CAMERAS` variable so `start_teleop` / `record_episodes` can run headless: `make start_teleop CAMERAS="{}"` (Makefile)
  - Hardware bringup section in README Quick Start: `setup_hardware → find_port → install_udev → bringup → calibrate_arms`
  - Pre-flight info block in `make bringup` output (find_port / install_udev / port env vars)
  - `docs/hardware/bringup.md` §6 and §7 now surface per-arm and CAMERAS hints
  - `CONTRIBUTING.md` make-command table annotates `calibrate_arms`, `start_teleop`, `record_episodes` with the new alternatives

### Changed

- **`make start_foxglove`** no longer hard-codes camera flags inline — references the new `FOXGLOVE_CAM_FLAGS` variable instead, matching the `CAMERAS` pattern used by `start_teleop` / `record_episodes`.
- **`setup_hardware` Makefile target**: tries PyPI wheels first via `uv sync --group lerobot --group foxglove`; falls back to `setup_hardware_deps` (sudo system build deps) only if wheel install fails. Removes blanket sudo prompt on first install.
- **`lerobot-*` CLIs invoked via `uv run`**: `find_port`, `calibrate_arm_*`, `start_teleop`, `record_episodes`, `train_policy` no longer require manual `source .venv/bin/activate` (fixes `lerobot-find-port: command not found`)
- **`.PHONY`** expanded to cover all hardware + per-arm targets

### Removed

- `DualArmController.start_teleoperation()` no-op stub from `src/so101/arms.py`. The method only validated inputs and logged `(stub)` — real teleop is invoked via `make start_teleop` / `lerobot-teleoperate`. Corresponding `TestTeleoperation` class removed from `tests/so101/test_arms.py`.

### Security

- **Resolved 25 of 28 Dependabot alerts (10 of 12 high)** by dropping the `[tool.uv]`
  `exclude-newer` cap — every patched version was released after the 2026-04-11 pin, so
  no fix was reachable while it stood — and re-locking the affected packages:
  `starlette` 1.0.0 → 1.3.1 (5 alerts, 2 high; also raised `fastapi>=0.136.1`, the first
  line tracking starlette 1.x), `aiohttp` 3.13.5 → 3.14.1 (11), `gitpython` 3.1.46 →
  3.1.50 (5 high), `urllib3` 2.6.3 → 2.7.0 (2 high), `lxml` 6.0.3 → 6.1.1 (1 high),
  `idna` 3.11 → 3.18 (1). Only `starlette`/`idna` reach the deployed dashboard; the rest
  are pulled solely by optional ML/hardware groups.
- **`.github/dependabot.yaml`**: switched `pip` → `uv` ecosystem (the `pip` ecosystem
  does not update `uv.lock`, so transitive lockfile fixes were never proposed — the root
  cause of the backlog) and added grouped updates, `chore(deps)`/`chore(ci)` commit
  prefixes, and labels.
- **Known unfixed, tracked**: `torch` ≤2.12 (CVE-2025-3000, low) — no upstream patch
  exists; `diffusers` 0.35.2 (CVE-2026-45804 / CVE-2026-44513, high ×2) — capped by
  `lerobot 0.4.4` (`diffusers<0.36.0`). Both are reachable only via the optional
  `lerobot`/`train` GPU group and require loading untrusted remote pipelines to exploit.

## [0.2.0] - 2026-04-16

### Added

- **Hardware bringup guide** (`docs/hardware/bringup.md`): step-by-step SO-101 calibration, teleoperation, firmware troubleshooting with 13-row diagnostic table
- **2-DOF pipette variant** (`docs/hardware/two-dof-pipette.md`): analysis of using SO-101 as 2-axis positioner with fixed electronic pipette mount
- **Mixed-firmware patch tool** (`src/so101/cli/patch_lerobot.py`): monkey-patches lerobot 0.4.4 to tolerate STS3215 servos with mixed firmware (3.9 + 3.10). Entry point: `so101-patch-lerobot`
- **Servo scan tool** (`src/so101/cli/scan_servos.py`): pre-calibration sanity check reporting servo IDs and firmware versions. Entry point: `so101-scan-servos`
- **`[project.scripts]` entry points**: `so101-demo`, `so101-coord`, `so101-scan-servos`, `so101-patch-lerobot` — replaces loose `scripts/` directory
- **Makefile targets**: `find_port`, `scan_servos`, `install_udev`, `bringup`, `patch_lerobot`, `patch_lerobot_revert`
- **Opt-in `lerobot` pytest marker** for patch compatibility guard tests (`tests/integration/test_patch_lerobot_compat.py`)
- **9 orphaned docs** added to CONTRIBUTING.md documentation hierarchy table

- **Prusa MK4 slicer profiles** (4 new `.ini` files under `src/hardware/slicer/profiles/`): `prusa_mk4_pla_02mm` (production PLA/PLA+), `prusa_mk4_pla_prototype` (fast 0.3mm fit-check), `prusa_mk4_pla_prototype_supports` (with auto-supports), `prusa_mk4_tpu_02mm` (TPU 95A)
- **PrusaLink API operations reference** (`docs/hardware/prusa-mk4-ops.md`): endpoint catalog, digest auth, upload + print-after-upload curl examples, CAD-to-print pipeline
- **dPette+ 3D scan reference data**: `hardware/scans/dpette/0410_02_mesh.{ply,stl}` (1:1 mm Revopoint scan) + `hardware/scans/dpette/README.md` (provenance, scale, intended use)
- **5 new dPette CAD parts** (build123d, ported from Antonio Lamb's PR #48 CadQuery source): `dpette_handle` (U-bracket single-channel mount), `dpette_cam_arm` (M6 horn radial arm), `dpette_tip_release` (L-bracket ejector station), `dpette_multi_handle` (Ø32mm split-bore clamp — scan-derived, replaces SO-101 bottom jaw), `dpette_ejector_lever` (M6-horn lever, replaces SO-101 top jaw, ~175N)
- **`diagramforge` submodule** (<https://github.com/qte77/diagramforge>) for interactive SVG/drawio design with Claude Code and other agents
- `scan_source` optional field in `src/hardware/parts.json` for scan-derived parts — queryable provenance pointing at `hardware/scans/` inputs
- `Hardware Asset Layout` section in `docs/architecture.md` describing the code/assets split and scan data as optional CAD input
- `ASSETS_DIR` constant in `tests/_paths.py` for the new top-level `hardware/` path
- E2E workflow orchestration (`src/so101/workflow.py`): UC1 pipetting (single/row/col/full plate), UC2 fridge ops, UC3 tool interchange, UC4 demo mode, UC5 gantry-based pipetting
- Multi-backend pipette architecture: `PipetteProtocol` interface with `DigitalPipette` (DIY) and `ElectronicPipette` (AELAB dPette 7016 / DLAB dPette+) backends
- `XZGantry` dedicated pipetting arm controller — 2-axis alternative to SO-101, supports Pololu Maestro + Pico W serial protocols
- `BentoLab` portable PCR thermocycler module — lid, programs, status
- Config-driven named positions in `configs/arms.yaml` with `move_to_named()`, `execute_sequence()`, `start_teleoperation()`
- Position sequence pipetting: `pipette_well` uses approach/lower patterns
- `PlateLayout` config loader and `create_workflow_context()` factory wiring all modules from YAML
- `--use-case` CLI dispatch in `run_demo.py`
- Dashboard: `run_workflow` WebSocket command, full component lifespan wiring
- `src/hardware/parts.json` manifest as single source of truth for all printable parts
- `src/hardware/render.py` unified runner — dispatches build123d or OpenSCAD per manifest
- Slicer validation script (`src/hardware/slicer/validate.py`) with graceful fallback when slicer unavailable
- STL mesh integrity check (`check_mesh_integrity`, `--structural` CLI flag)
- Position teaching (`teach_position`) and config persistence (`save_config`) for XZ gantry
- Makefile targets: `setup_cad`, `setup_scad`, `setup_slicer`, `render_parts`, `check_prints`, `render_all`

### Changed

- **Scripts moved** from `scripts/` to `src/so101/cli/` as proper package entry points via hatchling
- **Integration tests refactored** to call `main()` directly (not subprocess) — coverage: 75% → 80%
- **ELN client** (`src/so101/eln_client.py`): 10 inline pyright ignores replaced with single `Any` cast on untyped `elabapi_python` import
- **Coverage gate** enforced at 80% in CI (`--cov-fail-under=80`)
- **Code / assets split**: generated STL + SVG outputs moved from `src/hardware/{stl,svg}/` to top-level `hardware/{stl,svg}/`. Code (CAD scripts, `render.py`, `slicer/`, `parts.json`) stays under `src/hardware/`. New top-level `hardware/scans/` for reference 3D scan data. `render.py`, `slicer/validate.py`, `cad/util/export.py`, `tests/_paths.py` all updated to resolve asset paths via a new `ASSETS_DIR` anchor.
- `src/hardware/README.md` restructured: removed duplicated Parts Table (→ points at `parts.json` as single source of truth + `jq` query examples) and duplicated layout description (→ points at `docs/architecture.md`). Added dPette+ 8-ch Mount + dPette single-channel Mount + Scan Reference Data assembly sections, Prusa MK4 slicer profile catalog.
- `parts.json` `notes` fields trimmed to short descriptive labels — provenance prose moved to commit history per DRY.
- `README.md` (root): Workspace Layout image link updated to `hardware/svg/system_overview.svg`
- `dpette_cam_arm` tip geometry: `Sphere` → `Cylinder` (functionally equivalent; Sphere+Cylinder composites broke build123d's 2D SVG projection)
- CAD backend migrated from CadQuery to build123d (Python 3.13 compatible, algebraic operators) — all 13 CAD files ported
- `app/` directory restructure: `src/biolab/` → `src/so101/` (library modules) + `src/so101/cli/` (CLI scripts), `src/dashboard/` → `src/dashboard/`
- `hardware/cad/` reorganised into topic folders: `so101/`, `dpette/`, `labware/`, `deferred/`, `util/`
- `pipette_mount` redesigned for dPette barrel (ejector button cutout) — was digital-pipette-v2
- `tip_ejection_bar` redesigned from side-lever bar to top-button post to match dPette mechanism
- XZ gantry parts (`xz_gantry_frame`, `xz_carriage`) deferred — focus on SO-101 arm-held dPette
- Dashboard wired to real `DualArmController` + `SafetyMonitor` via FastAPI lifespan
- `workflow.py` now accepts `PipetteProtocol` instead of concrete `DigitalPipette`
- `camera.py`: cv2 import deferred to `start()` for headless environments
- Makefile: `.SILENT` / `.ONESHELL` / `.DEFAULT_GOAL`, `# MARK:` grouped help

### Fixed

- Fenced code blocks missing language specifier (MD040) in bringup.md and prusa-mk4-ops.md
- Hardcoded `/tmp` paths in test_eln_client.py replaced with `tmp_path` fixture (Bandit B108)
- `feetechrc.com` excluded from lychee link checker (TLS handshake failure in CI)
- `src/hardware/cad/util/export.py` (`export_part`): handles `ShapeList` results from build123d boolean operations via a `_to_compound` coercion helper (disconnected shapes no longer fail with `AttributeError: ShapeList has no wrapped`)
- `tests/so101/test_arms.py`: pre-existing ruff drift — B007 (unused loop var `arm_id` → `_arm_id`) + RUF043 (non-raw regex `"[Ll]eader"` → `r"[Ll]eader"` in `pytest.raises(match=...)`)
- `arms.py`: stub-safe `get_observation` / `send_action` when LeRobot unavailable
- `pipette.py`: fill state tracking with over-aspiration / over-dispense guards

### Infrastructure

- `tests/hardware/test_scad_svg.py`: resolves SVG paths via `ASSETS_DIR` (top-level `hardware/svg/`) instead of `HARDWARE_DIR` (`src/hardware/svg/`) — follows the code/assets split
- `AGENT_LEARNINGS.md` entries: `make test` excludes hardware/network tests by default via `pyproject.toml:79` `addopts`; git log direction hazard — always use explicit `A..B` ranges instead of one-sided `git log B -N`
- Test suite: Hypothesis property tests (well coords, parse_well roundtrip, aspirate/dispense, joint limits)
- Quality gates: pytest coverage, pyright type checking, ruff lint (N/UP rules), cognitive complexity (max 15/function) via complexipy
- Docs: `docs/architecture.md`, `docs/UserStory.md`, `docs/demo-scenarios.md`, `docs/hardware/BOM.md`, `docs/research.md`, `docs/roadmap.md`
- Documentation hierarchy declared in `CONTRIBUTING.md` with authority table; YAML frontmatter on all docs
- `.github/` infrastructure: issue templates, PR template, dependabot, CI workflows (ruff, pytest, CodeQL, link checker)
- `.devcontainer/devcontainer.json` for Codespace dev environment
- `.claude/` harness: settings, rules, statusline; plugins for python-dev, docs-governance, commit-helper, codebase-tools
- `LICENSE` (Apache-2.0)

## [0.1.0-alpha] — initial prototype

- SO-101 dual-arm controller + LeRobot integration (stub-safe)
- Workspace-frame coordinate commands, safety monitor watchdog
- FastAPI dashboard with WebSocket command channel
- OpenSCAD CAD pipeline for initial parts

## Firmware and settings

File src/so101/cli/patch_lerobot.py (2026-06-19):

#!/usr/bin/env python3
"""Patch lerobot to tolerate mixed STS3215 firmware versions.

STS3215 servos may ship with mixed firmware versions (e.g. 3.9 and 3.10).
LeRobot 0.4.4 has two problems with this:

1. _assert_same_firmware() raises RuntimeError if versions differ
2. sync_read fails with "Incorrect status packet!" because firmware 3.9
   returns a slightly different packet format, corrupting the batch response

This script patches the installed lerobot package in-place:
- Firmware check: warn instead of raise
- sync_read: fall back to sequential individual reads on failure

Re-run after `uv sync` reinstalls lerobot.

Usage:
    uv run so101-patch-lerobot           # apply both patches
    uv run so101-patch-lerobot --revert  # restore originals
"""

from __future__ import annotations

import sys
from pathlib import Path

SITE_PACKAGES = Path(
    sys.prefix,
    "lib",
    f"python{sys.version_info.major}.{sys.version_info.minor}",
    "site-packages",
    "lerobot",
    "motors",
)

FEETECH_PY = SITE_PACKAGES / "feetech" / "feetech.py"
MOTORS_BUS_PY = SITE_PACKAGES / "motors_bus.py"

# --- Patch 1: firmware version check ---

FW_ORIGINAL = """\
    def _assert_same_firmware(self) -> None:
        firmware_versions = self._read_firmware_version(self.ids, raise_on_error=True)
        if len(set(firmware_versions.values())) != 1:
            raise RuntimeError(
                "Some Motors use different firmware versions:"
                f"\\n{pformat(firmware_versions)}\\n"
                "Update their firmware first using Feetech's software. "
                "Visit https://www.feetechrc.com/software."
            )"""

FW_PATCHED = """\
    def _assert_same_firmware(self) -> None:
        firmware_versions = self._read_firmware_version(self.ids, raise_on_error=True)
        if len(set(firmware_versions.values())) != 1:
            import logging
            logging.getLogger("lerobot.motors.feetech").warning(
                "Mixed firmware versions detected (PATCHED — continuing anyway):"
                f"\\n{pformat(firmware_versions)}\\n"
                "For production use, update firmware via Feetech FD software."
            )"""

# --- Patch 2: sync_read fallback to sequential reads ---

SYNC_ORIGINAL = """\
    def _sync_read(
        self,
        addr: int,
        length: int,
        motor_ids: list[int],
        *,
        num_retry: int = 0,
        raise_on_error: bool = True,
        err_msg: str = "",
    ) -> tuple[dict[int, int], int]:
        self._setup_sync_reader(motor_ids, addr, length)
        for n_try in range(1 + num_retry):
            comm = self.sync_reader.txRxPacket()
            if self._is_comm_success(comm):
                break
            logger.debug(
                f"Failed to sync read @{addr=} ({length=}) on {motor_ids=} ({n_try=}): "
                + self.packet_handler.getTxRxResult(comm)
            )

        if not self._is_comm_success(comm) and raise_on_error:
            raise ConnectionError(f"{err_msg} {self.packet_handler.getTxRxResult(comm)}")

        values = {id_: self.sync_reader.getData(id_, addr, length) for id_ in motor_ids}
        return values, comm"""

SYNC_PATCHED = """\
    _sync_read_warned = False  # PATCHED: suppress repeated warnings

    def _sync_read(
        self,
        addr: int,
        length: int,
        motor_ids: list[int],
        *,
        num_retry: int = 0,
        raise_on_error: bool = True,
        err_msg: str = "",
    ) -> tuple[dict[int, int], int]:
        self._setup_sync_reader(motor_ids, addr, length)
        for n_try in range(1 + num_retry):
            comm = self.sync_reader.txRxPacket()
            if self._is_comm_success(comm):
                break
            logger.debug(
                f"Failed to sync read @{addr=} ({length=}) on {motor_ids=} ({n_try=}): "
                + self.packet_handler.getTxRxResult(comm)
            )

        if self._is_comm_success(comm):
            values = {id_: self.sync_reader.getData(id_, addr, length) for id_ in motor_ids}
            return values, comm

        # PATCHED: fall back to sequential individual reads (mixed firmware workaround)
        if not self._sync_read_warned:
            logger.warning(
                f"sync_read failed on {motor_ids=}, using sequential reads "
                "(mixed firmware workaround, this message shown once)"
            )
            self._sync_read_warned = True
        values = {}
        last_comm = comm
        for motor_id in motor_ids:
            val, c, error = self._read(
                addr, length, motor_id, num_retry=num_retry, raise_on_error=False
            )
            if self._is_error(error):
                logger.debug(
                    f"Transient servo error on {motor_id=}: "
                    + self.packet_handler.getRxPacketError(error)
                )
            # Clamp to valid STS3215 range (0-4095) — glitchy reads can return negatives
            val = max(0, min(4095, val))
            values[motor_id] = val
            last_comm = c
        return values, last_comm"""


# --- Patch 3: clamp calibration range values before writing to servo EPROM ---

CAL_ORIGINAL = """\
    def write_calibration(self, calibration_dict: dict[str, MotorCalibration], cache: bool = True) -> None:
        for motor, calibration in calibration_dict.items():
            if self.protocol_version == 0:
                self.write("Homing_Offset", motor, calibration.homing_offset)
            self.write("Min_Position_Limit", motor, calibration.range_min)
            self.write("Max_Position_Limit", motor, calibration.range_max)"""

CAL_PATCHED = """\
    def write_calibration(self, calibration_dict: dict[str, MotorCalibration], cache: bool = True) -> None:
        for motor, calibration in calibration_dict.items():
            if self.protocol_version == 0:
                self.write("Homing_Offset", motor, calibration.homing_offset)
            # PATCHED: clamp to valid range — glitchy reads can produce negatives
            range_min = max(0, min(4095, calibration.range_min))
            range_max = max(0, min(4095, calibration.range_max))
            self.write("Min_Position_Limit", motor, range_min)
            self.write("Max_Position_Limit", motor, range_max)"""


def _apply_patch(path: Path, original: str, patched: str, name: str, *, revert: bool) -> bool:
    """Apply or revert a single patch. Returns True if a change was made."""
    if not path.exists():
        print(f"  SKIP {name}: {path} not found")
        return False

    source = path.read_text()

    if revert:
        if patched not in source:
            print(f"  SKIP {name}: patch not applied")
            return False
        path.write_text(source.replace(patched, original))
        print(f"  REVERTED {name}: {path}")
        return True

    if patched in source:
        print(f"  SKIP {name}: already patched")
        return False
    if original not in source:
        print(f"  ERROR {name}: expected code not found (lerobot version may differ)")
        return False
    path.write_text(source.replace(original, patched))
    print(f"  PATCHED {name}: {path}")
    return True


def main() -> None:
    """Apply or revert lerobot patches based on CLI flags."""
    revert = "--revert" in sys.argv
    action = "Reverting" if revert else "Applying"
    print(f"{action} lerobot patches for mixed firmware workaround...")

    results = [
        _apply_patch(FEETECH_PY, FW_ORIGINAL, FW_PATCHED, "firmware_check", revert=revert),
        _apply_patch(
            MOTORS_BUS_PY, SYNC_ORIGINAL, SYNC_PATCHED, "sync_read_fallback", revert=revert
        ),
        _apply_patch(FEETECH_PY, CAL_ORIGINAL, CAL_PATCHED, "calibration_clamp", revert=revert),
    ]

    if not any(results):
        print("No changes made.")
    else:
        print("Done. Re-run after `uv sync` reinstalls lerobot.")


if __name__ == "__main__":
    main()

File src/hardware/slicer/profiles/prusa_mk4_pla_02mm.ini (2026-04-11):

# PrusaSlicer production profile: Prusa MK4 — PLA/PLA+ 0.2mm
# Optimized for functional robotics parts (tool cones, mounts, cradles, docks)
# Printer: Original Prusa MK4 (Nextruder, input shaper)
# Network: 192.168.1.86 / prusa-mk4.local
#
# Usage:
#   prusa-slicer --load app/hardware/slicer/profiles/prusa_mk4_pla_02mm.ini \
#                --export-gcode -o output.gcode input.stl

# Layer
layer_height = 0.2
first_layer_height = 0.2

# Walls — 3 perimeters for functional strength
perimeters = 3
external_perimeters_first = 0
extra_perimeters = 1
thin_walls = 1

# Infill — 25% grid for structural parts
fill_density = 25%
fill_pattern = grid
top_fill_pattern = monotonic
bottom_fill_pattern = monotonic
infill_every_layers = 1
infill_overlap = 25%

# Top/bottom — 5 solid layers for strength + water tightness
top_solid_layers = 5
bottom_solid_layers = 4

# Speed — MK4 input shaper allows higher speeds safely
perimeter_speed = 100
external_perimeter_speed = 60
infill_speed = 150
solid_infill_speed = 100
top_solid_infill_speed = 50
first_layer_speed = 30
travel_speed = 250
travel_speed_z = 12

# Support — off by default (most biolab parts are designed support-free)
support_material = 0
support_material_auto = 0
support_material_threshold = 55

# Brim — 3mm for bed adhesion on functional parts
skirts = 0
brim_width = 3

# Seam — aligned for consistent dimensional accuracy
seam_position = aligned

# Overhangs
overhangs = 1
bridge_speed = 30
bridge_flow_ratio = 0.95

# Elephant foot compensation (0.2mm typical for MK4 textured sheet)
elefant_foot_compensation = 0.2

# Filament
filament_type = PLA
temperature = 215
first_layer_temperature = 220
bed_temperature = 60
first_layer_bed_temperature = 60

# Cooling — PLA needs aggressive cooling
fan_always_on = 1
min_fan_speed = 100
max_fan_speed = 100
bridge_fan_speed = 100
disable_fan_first_layers = 1
cooling = 1
min_print_speed = 15

# Retraction — Nextruder direct drive
retract_length = 0.4
retract_speed = 35
deretract_speed = 25
retract_lift = 0.2
retract_before_travel = 1
wipe = 1

# Printer
nozzle_diameter = 0.4
bed_shape = 0x0,250x0,250x210,0x210
max_print_height = 220
min_layer_height = 0.07
max_layer_height = 0.32
gcode_flavor = marlin2

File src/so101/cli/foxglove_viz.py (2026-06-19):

r"""Live SO-101 arm visualization via Foxglove WebSocket + optional MCAP.

Reads joint positions from a real SO-101 follower arm, computes forward
kinematics via URDF, and streams transforms + camera frames to Foxglove.

Requires dependency groups: ``uv sync --group foxglove --group lerobot``

URDF and STL assets are maintained upstream:
https://github.com/foxglove/foxglove-sdk/tree/main/python/foxglove-sdk-examples/so101-visualization/SO101

Usage::

    python -m so101.foxglove_viz \
        --robot.port=/dev/ttyACM1 --robot.id=arm_a \
        --robot.wrist_cam_id=2 --robot.env_cam_id=0
"""

from __future__ import annotations

import argparse
import datetime
import logging
import math
import sys
import time
from pathlib import Path
from typing import Any

logger = logging.getLogger(__name__)

RATE_HZ = 30.0
WORLD_FRAME_ID = "world"
BASE_FRAME_ID = "base_link"
URDF_FILE = "SO101/so101_new_calib.urdf"


def _parse_args() -> argparse.Namespace:
    parser = argparse.ArgumentParser(
        description="SO-101 live visualization via Foxglove",
        formatter_class=argparse.ArgumentDefaultsHelpFormatter,
    )
    robot = parser.add_argument_group("robot")
    robot.add_argument("--robot.port", required=True, dest="port")
    robot.add_argument("--robot.id", required=True, dest="robot_id")
    robot.add_argument("--robot.wrist_cam_id", type=int, dest="wrist_cam_id")
    robot.add_argument("--robot.env_cam_id", type=int, dest="env_cam_id")

    out = parser.add_argument_group("output")
    out.add_argument("--output.write_mcap", action="store_true", dest="write_mcap")
    out.add_argument("--output.mcap_path", dest="mcap_path")
    out.add_argument("--urdf", default=URDF_FILE, help="Path to SO-101 URDF file")
    return parser.parse_args()


def _setup_camera(cam_id: int, topic: str) -> tuple[Any, Any]:
    """Connect camera and create Foxglove image channel."""
    from foxglove.channels import RawImageChannel
    from lerobot.cameras import ColorMode, Cv2Rotation
    from lerobot.cameras.opencv import OpenCVCamera, OpenCVCameraConfig

    cfg = OpenCVCameraConfig(
        index_or_path=cam_id,
        fps=30,
        width=640,
        height=480,
        color_mode=ColorMode.RGB,
        rotation=Cv2Rotation.NO_ROTATION,
    )
    camera = OpenCVCamera(cfg)
    camera.connect()
    channel = RawImageChannel(topic=topic)
    return camera, channel


def _publish_frame(camera: Any, channel: Any) -> None:
    """Read one frame and publish to Foxglove."""
    from foxglove.messages import RawImage

    frame = camera.async_read(timeout_ms=200)
    channel.log(
        RawImage(
            data=frame.tobytes(),
            width=frame.shape[1],
            height=frame.shape[0],
            step=frame.shape[1] * 3,
            encoding="rgb8",
        ),
    )


_JOINT_KEYS = [
    "shoulder_pan",
    "shoulder_lift",
    "elbow_flex",
    "wrist_flex",
    "wrist_roll",
]


def _read_joints(obs: Any, positions: dict[str, float]) -> None:
    """Update joint positions from follower observation (degrees → radians)."""
    for key in _JOINT_KEYS:
        positions[key] = math.radians(obs.get(f"{key}.pos", 0.0))
    positions["gripper"] = (obs.get("gripper.pos", 0.0) - 10) / 100.0 * math.pi


def _build_transforms(robot_model: Any) -> list[Any]:
    """Compute per-joint transforms from URDF forward kinematics."""
    from foxglove.messages import FrameTransform, Quaternion, Vector3
    from scipy.spatial.transform import Rotation

    transforms: list[Any] = [
        FrameTransform(
            parent_frame_id=WORLD_FRAME_ID,
            child_frame_id=BASE_FRAME_ID,
            translation=Vector3(x=0.0, y=0.0, z=0.0),
            rotation=Quaternion(x=0.0, y=0.0, z=0.0, w=1.0),
        ),
    ]
    for joint in robot_model.robot.joints:
        t_local = robot_model.get_transform(
            frame_to=joint.child,
            frame_from=joint.parent,
        )
        trans = t_local[:3, 3]
        quat = Rotation.from_matrix(t_local[:3, :3]).as_quat()
        transforms.append(
            FrameTransform(
                parent_frame_id=joint.parent,
                child_frame_id=joint.child,
                translation=Vector3(
                    x=float(trans[0]),
                    y=float(trans[1]),
                    z=float(trans[2]),
                ),
                rotation=Quaternion(
                    x=float(quat[0]),
                    y=float(quat[1]),
                    z=float(quat[2]),
                    w=float(quat[3]),
                ),
            ),
        )
    return transforms


def _try_camera(cam_id: int | None, topic: str) -> tuple[Any, Any]:
    """Try to connect a camera; return (None, None) on failure or if not requested."""
    if cam_id is None:
        return None, None
    try:
        return _setup_camera(cam_id, topic)
    except Exception:
        logger.warning("Camera %s (device %d) failed", topic, cam_id, exc_info=True)
        return None, None


def _safe_publish(camera: Any, channel: Any) -> None:
    """Publish a camera frame, silently ignoring read errors."""
    if camera is None or channel is None:
        return
    try:
        _publish_frame(camera, channel)
    except Exception:
        logger.debug("Camera read failed", exc_info=True)
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

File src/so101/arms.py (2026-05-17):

"""Dual SO-101 arm controller wrapping LeRobot API.

Manages two follower arms and optional leader arm for teleoperation.
"""

from __future__ import annotations

import logging
from typing import TYPE_CHECKING, Any, Self

if TYPE_CHECKING:
    from pathlib import Path

import yaml
from pydantic import BaseModel, ConfigDict
from pydantic_settings import BaseSettings, SettingsConfigDict

from so101.plate import parse_well_name

logger = logging.getLogger(__name__)


class ArmConfig(BaseModel):
    """Configuration for a single SO-101 arm."""

    model_config = ConfigDict(strict=True)

    arm_id: str
    port: str
    role: str  # "follower" or "leader"
    cameras: dict[str, Any] = {}


class DualArmConfig(BaseSettings):
    """Configuration for the dual-arm setup."""

    model_config = SettingsConfigDict(strict=True)

    arm_a: ArmConfig
    arm_b: ArmConfig
    leader: ArmConfig | None = None
    positions: dict[str, list[float]] = {}

    @classmethod
    def from_yaml(cls, path: str | Path) -> Self:
        """Load configuration from YAML file."""
        with open(path) as f:
            data = yaml.safe_load(f)
        return cls.model_validate(data)


class DualArmController:
    """Controls two SO-101 follower arms with optional leader for teaching.

    Usage:
        config = DualArmConfig.from_yaml("configs/arms.yaml")
        controller = DualArmController(config)
        controller.connect()
        controller.send_to_well("arm_a", "A1")
        controller.park_all()
        controller.disconnect()
    """

    def __init__(self, config: DualArmConfig) -> None:
        """Initialize with dual-arm configuration."""
        self.config = config
        self._connected = False
        self._stub_mode = False
        self._robots: dict[str, Any] = {}
        # Stub-mode action log: records every commanded action per arm so
        # stub runs (and tests) can observe what the controller sent without
        # touching real hardware. Latest entry == last commanded position.
        self._stub_action_log: dict[str, list[list[float]]] = {}

    @property
    def is_connected(self) -> bool:
        """Whether arms are currently connected."""
        return self._connected

    @property
    def is_stub_mode(self) -> bool:
        """Whether the controller is running in stub mode."""
        return self._stub_mode

    @property
    def arm_ids(self) -> list[str]:
        """IDs of configured follower arms."""
        return [
            cfg.arm_id for cfg in [self.config.arm_a, self.config.arm_b] if cfg.role == "follower"
        ]

    def connect(self) -> None:
        """Connect to all configured arms via LeRobot."""
        import os

        if os.environ.get("SO101_STUB_MODE") == "1":
            logger.warning("SO101_STUB_MODE=1 — running in stub mode")
            self._stub_mode = True
            self._connected = True
            return
        try:
            from lerobot.robots.so_follower import (  # pyright: ignore[reportMissingImports]
                SO101Follower,  # pyright: ignore[reportUnknownVariableType]
                SO101FollowerConfig,  # pyright: ignore[reportUnknownVariableType]
            )
        except ImportError:
            logger.warning("lerobot not installed — running in stub mode")
            self._stub_mode = True
            self._connected = True
            return

        for arm_cfg in [self.config.arm_a, self.config.arm_b]:
            if arm_cfg.role != "follower":
                continue
            robot_config: Any = SO101FollowerConfig(  # pyright: ignore[reportUnknownVariableType]
                port=arm_cfg.port,
                id=arm_cfg.arm_id,
                cameras=arm_cfg.cameras,
            )
            robot: Any = SO101Follower(robot_config)  # pyright: ignore[reportUnknownVariableType]
            robot.connect()  # pyright: ignore[reportUnknownMemberType]
            self._robots[arm_cfg.arm_id] = robot
            logger.info("Connected arm %s on %s", arm_cfg.arm_id, arm_cfg.port)

        self._connected = True

    def disconnect(self) -> None:
        """Disconnect all arms."""
        for arm_id, robot in self._robots.items():
            robot.disconnect()
            logger.info("Disconnected arm %s", arm_id)
        self._robots.clear()
        self._stub_action_log.clear()
        self._connected = False
        self._stub_mode = False

    def get_observation(self, arm_id: str) -> dict[str, Any]:
        """Read current joint positions and camera frames from an arm.

        Args:
            arm_id: Which arm to read from.

        Returns:
            Dict with joint positions and camera data.

        Raises:
            ValueError: If arm_id is not a configured follower arm.
        """
        if self._stub_mode:
            if arm_id not in self.arm_ids:
                raise ValueError(f"Unknown arm: {arm_id}")
            history = self._stub_action_log.get(arm_id, [])
            last_joints = list(history[-1]) if history else []
            return {
                "joints": last_joints,
                "stub": True,
                "history": [list(a) for a in history],
            }
        if arm_id not in self._robots:
            raise ValueError(f"Unknown arm: {arm_id}")
        return self._robots[arm_id].get_observation()

    def send_action(self, arm_id: str, action: Any) -> None:  # noqa: ANN401
        """Send a joint-space action to an arm.

        Args:
            arm_id: Which arm to control.
            action: Action tensor (joint positions).

        Raises:
            ValueError: If arm_id is not a configured follower arm.
        """
        if self._stub_mode:
            if arm_id not in self.arm_ids:
                raise ValueError(f"Unknown arm: {arm_id}")
            logger.debug("Stub send_action(%s, %s)", arm_id, action)
            self._stub_action_log.setdefault(arm_id, []).append(list(action))
            return
        if arm_id not in self._robots:
            raise ValueError(f"Unknown arm: {arm_id}")
        self._robots[arm_id].send_action(action)

    def send_to_well(self, arm_id: str, well_name: str) -> None:
        """Move an arm to a 96-well plate position.

        Args:
            arm_id: Which arm to move.
            well_name: Well name like 'A1', 'H12'.

        Raises:
            ValueError: If well_name is invalid or arm_id unknown.
        """
        well = parse_well_name(well_name)
        logger.info("Moving %s to well %s (%.2f, %.2f mm)", arm_id, well.name, well.x_mm, well.y_mm)
        # Use config well_approach position; fall back to zeros if not configured
        if "well_approach" in self.config.positions:
            joints = list(self.config.positions["well_approach"])
        else:
            joints = [0.0] * 6
        self.send_action(arm_id, joints)

    def move_to_named(self, arm_id: str, position_name: str) -> None:
        """Move an arm to a named position from config.
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

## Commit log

2026-03-25 PR ci: add GitHub infrastructure, devcontainer, RTK, badges, LICENSE (#1)
    * docs: add Apache-2.0 LICENSE file
    * ci: add devcontainer.json for Codespace dev environment
    * chore: add make setup_rtk target for RTK CLI install
    * chore: add RTK project config (telemetry off, tee failures)
    * fix: resolve ruff CI failures and add README badges
    * ci: add GitHub infrastructure and fix maintainability issues
    [arms.py, camera.py, coordinate_cmd.py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]
2026-03-25 PR feat: Sprint 2 — dashboard wiring, script tests, lychee fixes (#6)
    * fix: pass --config to lychee-action so .lychee.toml is used
    * fix: use regex patterns in lychee.toml exclude, add accept codes
    * fix: correct lychee.toml config format (top-level exclude array)
    * test: add coordinate_cmd and run_demo script tests (6 tests)
    * feat: wire dashboard to real controller and monitor (6 tests)
    * fix: resolve lychee link checker issues, add rtk init to setup_rtk
2026-03-25 PR docs: add hardware BOM with first-party sourced links (#7)
    * fix: exclude BOM vendor URLs from lychee (bot-blocked)
    * docs: add hardware BOM with first-party sourced links
2026-03-26 PR feat: E2E workflow orchestration — 4 use cases (#8)
    * feat: add E2E workflow orchestration with 4 use cases (23 tests)
2026-03-27 PR docs: research, CAD scripts, STL/SVG, CHANGELOG, frontmatter (#11)
    * Research doc: 45+ sources (community designs, papers, future vision)
    * CadQuery CAD scripts: 7 scripts → 10 STL + 8 SVG (all parts)
    * SVG theme: light/dark via prefers-color-scheme
    * System overview SVG in README
    * YAML frontmatter on all docs
    * CHANGELOG updated with Sprint 0-3 changes
    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
2026-04-04 fix(build): add Make version guard for .ONESHELL compatibility (#23)
    * feat(hardware): add OpenSCAD parametric scripts for all 3D-printed parts
    Port 7 CadQuery scripts to OpenSCAD (.scad) for printer-agnostic
    parametric STL generation. CadQuery generates geometrically correct
    STLs but has no awareness of FDM printing constraints.
    Parts: tool_changer, tool_dock, pipette_mount, plate_holder,
    fridge_hook, tip_rack_holder, gripper_tips.
    * feat(hardware): add PrusaSlicer CLI printability validation
    validate.py wraps PrusaSlicer subprocess with 120s timeout and
    graceful fallback when slicer unavailable. Parses output for
    overhang/unsupported regi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
    [fridge_hook.scad, gripper_tips.scad, pipette_mount.scad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]
2026-04-04 feat(hardware): OpenSCAD + PrusaSlicer printability pipeline (#13)
    overhang/unsupported region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
2026-04-04 feat(hardware): CadQuery + PrusaSlicer pipeline with graceful fallbacks (#25)
    * feat(slicer): OrcaSlicer→PrusaSlicer fallback chain with xvfb headless workaround
    validate.py now tries OrcaSlicer first, falls back to PrusaSlicer.
    On OrcaSlicer segfault without DISPLAY, retries with xvfb-run.
    Added OrcaSlicer JSON profiles alongside existing PrusaSlicer INI.
    7 new tests covering fallback discovery, profile selection, and xvfb retry.
    * feat(cad): CadQuery primary with OpenSCAD fallback, render_parts target
    render_scad renamed to render_parts with runtime CadQuery/OpenSCAD
    fallback. tool_changer.py now exports per-tool SVGs. setup_slicer
    updat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
    [tool_changer.py]
2026-04-04 refactor: pin Python 3.12, add setup_all + VERBOSE flag (#28)
    * refactor: pin Python >=3.12 (CadQuery + LeRobot intersection)
    CadQuery requires <=3.12, LeRobot requires >=3.12. Pin to >=3.12 as
    the only version satisfying all deps. Drops backport packages
    (exceptiongroup, tomli, backports-asyncio-runner) from lockfile.
    Bumps exclude-newer to 2026-04-04.
    * ci: update devcontainer and workflows to Python 3.12
    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
2026-04-04 feat(hardware): manifest-driven part generation pipeline (#29)
    * feat(hardware): add parts.json manifest as single source of truth
    Defines all 10 parts with name, STL/SVG filenames, CadQuery script,
    OpenSCAD script, scad_args, and shape classification. Replaces
    scattered hardcoded filenames across Makefile and test files.
    * refactor(build): manifest-driven render.py replaces hardcoded Makefile
    render.py reads hardware/parts.json to dispatch CadQuery or OpenSCAD.
    Makefile render_parts reduced from 27 lines to 1. Auto-detects backend,
    runs theme_svgs.py after generation. Fixes stale OrcaSlicer comment.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
2026-04-09 feat: dual-path architecture, dPette integration, CAD reorg (#41)
    Multi-backend pipette system:
    - PipetteProtocol interface with DigitalPipette (DIY) and ElectronicPipette
    (AELAB dPette 7016 / DLAB dPette+) backends
    - Modular driver loading: imports dpette package when available, stubs otherwise
    - Backend selected via configs/pipette.yaml
    New modules:
    - XZGantry controller with Pololu Maestro / Pico W serial protocols,
    position teaching, config persistence (deferred from immediate use)
    - BentoLab portable PCR thermocycler (lid, programs, status, stub mode)
    - UC5 gantry-based pipetting workflow (uc5_gantry_pipette, uc5_gantry_strip)
    Hardware parts (CadQuery, organized by topic):
    - so101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
    [96well_plate_holder.stl, dpette_multi_cradle.stl, dpette_single_cradle.stl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]
2026-04-09 refactor: topic folders for stl/svg/scad matching cad/ structure (#42)
    * refactor: topic folders for stl/, svg/, scad/ matching cad/ structure
    Organized all hardware output directories into consistent topic folders:
    - so101/: arm end-effectors (tool cones, dock, mount, gripper, hook)
    - dpette/: pipette accessories (cradles, tip ejection post)
    - labware/: universal holders (plate, tip rack)
    - deferred/: XZ gantry parts (future scope)
    Moved hardware/stl/README.md → hardware/README.md (simpler SVG paths).
    Updated all CAD export paths, parts.json, render.py (mkdir for subdirs),
    stl_to_svg.py and theme_svgs.py (recursive glob). Fixed audit issues:
    stale digital-pipette-v2 refs, BOM TBD marker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
    [96well_plate_holder.stl, dpette_multi_cradle.stl, dpette_single_cradle.stl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]
2026-04-11 feat: Phase 2 — CAD migration, app/ restructure, TDD overhaul, docs cleanup
    Squash of 50 commits across six logical phases. See PR #47 for the full
    granular history; #45 and #46 are superseded (their commits are subsets
    contained in this merge).
    This commit supersedes the legacy hardware/ directory tree and the
    initial tests/test_*.py suite — replaced by app/hardware/** and
    tests/so101/** respectively. 27 legacy files are removed.
    ## CAD pipeline refactor (supersedes #45)
    - Migrate CadQuery → build123d (BREP kernel, Python 3.13 ready, algebraic ops)
    - Port all 13 CAD scripts; shared export_part() helper deduplicates 11 files
    - Dual-slicer validation: CuraEngine (preferred) + PrusaSl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
    [96well_plate_holder.stl, dpette_multi_cradle.stl, dpette_single_cradle.stl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]
2026-04-11 docs(learnings): add pytest default exclusions + git log direction hazard
    Two agent-learning entries discovered during Phase 2 cleanup investigation
    (2026-04-11), both verified TRUE against current repo state before landing.
    1. `make test` silently excludes hardware + network tests by default.
    The Makefile target is `uv run pytest $(PYTEST_QUIET)` with no marker
    override — looks like it runs everything but doesn't. The exclusion
    lives in pyproject.toml:79 under [tool.pytest.ini_options] as
    `addopts = "--strict-markers -m 'not hardware and not network'"`.
    An agent assuming make test runs all tests will be wrong.
    2. Git log direction hazard — `git log main -N` shows main's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
2026-04-11 feat(hardware): Antonio's MK4 + dPette+ work ported to build123d and our structure
    Integrate Antonio Lamb's (@antomicblitz) PR #43 and #48 contributions —
    build123d ports of his CadQuery CAD, Prusa MK4 slicer profiles, PrusaLink
    API docs, 3D scan reference data, and the diagramforge submodule pointer —
    into our post-Phase-2 structure. Zero CadQuery imports land on main; all
    CAD is build123d.
    Supersedes #43 and #48 (both CONFLICTING against post-Phase-2 main).
    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
    [0410_02_mesh.ply, 96well_plate_holder.stl, dpette_cam_arm.stl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]
2026-04-12 chore: hardening pass — CI gates, pyright, test overhaul (#51)
    * chore(cad): drop resolved TODO comments in tool_changer + gripper_tips
    Both TODOs marked as resolved by user 2026-04-11 — the dimensions they
    wrapped (WRIST_SCREW_PATTERN_RADIUS=9.0, WRIST_SCREW_DIAMETER=3.2 in
    tool_changer.py; FINGER_WIDTH=20.0, FINGER_DEPTH=8.0, TIP_THICKNESS=3.0,
    TIP_LENGTH=25.0 in gripper_tips.py) stand as the authoritative values.
    No geometry change — comment-only cleanup.
    * ci(workflows): enforce type/complexity/coverage gates + SHA pin actions
    Biggest gap the hardening audit surfaced: local `make validate` enforces
    pyright, complexipy, and coverage, but none of those gates exist in CI.
    Violatio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
    [arms.py, pipette.py, safety.py]
2026-04-12 docs(bom): fix dead product URLs for Prusament PLA + Revopoint scanner (#52)
    - Prusament PLA Galaxy Black moved from shop.prusa3d.com to
    www.prusa3d.com/product/ (NFC spool variant)
    - Revopoint MINI discontinued, replaced by MINI 2 at new URL;
    bumped price range to $450–900
2026-04-12 chore: strict quality pass — pydantic + pyright + ruff + review (#57)
    * chore(deps): add pydantic + pydantic-settings[yaml] + types-PyYAML
    Runtime: pydantic>=2.10 (strict mode), pydantic-settings[yaml]>=2.7
    (BaseSettings with built-in YAML source for config loading).
    Dev: types-PyYAML>=6.0 (type stubs for pyright strict mode, Phase 5).
    pydantic is already a transitive dep via fastapi but needs to be
    explicit for pydantic-settings and to pin the minimum version.
    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
2026-04-12 test: close deferred test improvements (#54) (#58)
    * test(dashboard): cover WebSocket error paths + status endpoint
    Adds 4 tests: malformed JSON error response, unknown command
    handling, missing command key, and GET /api/status endpoint.
    Covers the error handling paths added in the WebSocket hardening
    commit.
    * test(camera): mock cv2 to cover start/stop/get_frame paths
    Adds 6 tests using mocked cv2.VideoCapture to exercise the cv2-
    dependent code paths without requiring real camera hardware.
    Covers start() camera opening, failed-open skip, stop() release,
    get_frame() success/failure, and multi-camera get_frames().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
2026-04-12 docs: add outlook research for platforms and integrations (#59)
    * docs: add outlook research — ceiling-mounted SO-101 on linear rail
    Feasibility study covering mechanical modifications (metal shoulder bracket,
    anti-backlash spring), rail options (OpenBuilds C-Beam, igus drylin), controller
    programmability (FluidNC, Grbl, ODrive, Klipper manual_stepper), software impact
    (URDF inversion, gravity comp sign flip, ACT retraining), and safety (fall
    protection, vibration settling, drip shielding).
    * docs: add outlook research — 3D printers & CNC as pipetting platforms
    Covers 9 conversion projects (Science Jubilee, PALH, BioCloneBot, MULA, etc.)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
2026-04-12 docs: restructure notes.md — split by purpose, DRY, rename (#65)
    * docs: extract CAD/sim/slicer tooling to hardware/cad-tooling.md
    Move CAD library comparison, OpenSCAD CLI, slicer CLI comparison,
    SO-101 simulation & digital twin, XLeRobot reference, validation
    pipeline, and STL files status from notes.md into a dedicated doc
    under docs/hardware/. No content changed, only relocated.
    * docs: move near-term actions from notes.md to roadmap.md
    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
2026-04-13 feat: add eLabFTW, PyLabRobot backend, Cartesian platform (#62, #63, #64) (#68)
    * feat: add eLabFTW ELN client with stub mode fallback (#62)
    TDD implementation of ElnClient wrapping elabapi-python SDK.
    Follows existing bento_lab.py pattern: strict pydantic config,
    from_yaml loader, graceful ImportError → stub mode degradation.
    16 tests: config validation, stub ops, mocked API calls, hypothesis fuzz.
    * feat: add PyLabRobot-compatible backend for SO-101 arms (#63)
    Implements SO101Backend wrapping DualArmController + PipetteProtocol
    with async interface matching PyLabRobot MachineBackend. Falls back
    to standalone class when pylabrobot is not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
    [cartesian_platform.py, eln_client.py, pylabrobot_backend.py]
2026-04-13 chore: add lerobot, foxglove dep groups; make wandb opt-in (#69)
    * chore: add lerobot, foxglove dep groups; make wandb opt-in
    Add dependency groups for SO-101 hardware operation:
    - lerobot: lerobot[feetech] for calibration, teleop, recording
    - train: lerobot[feetech] + wandb for policy training
    - foxglove: foxglove-sdk, scipy, yourdfpy for live 3D viz + MCAP
    Make wandb opt-in (WANDB=0 default) instead of hardcoded true.
    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
2026-04-13 feat: add lerobot, foxglove dep groups; stub mode fix (#72)
    * feat: add Foxglove live visualization for SO-101 arms
    Add foxglove_viz module and `make start_foxglove` target for real-time
    3D arm visualization + camera feeds via Foxglove WebSocket (port 8765).
    - foxglove_viz.py: reads join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
2026-04-13 chore: rename claude-code-utils-plugin references to claude-code-plugins (#73)
    🤖 Co-Authored-By: Claude <noreply@anthropic.com>
2026-04-16 docs: SO-101 hardware bringup + mixed-firmware patches (#75)
    Hardware bringup docs, mixed-firmware patches, tooling improvements.
    ## What's included (15 commits squashed)
    ### Firmware patches (app/so101/patch_lerobot.py)
    - 3 monkey-patches for mixed STS3215 firmware (FW check, sync_read
    fallback, calibration clamp)
    - Opt-in CI compat guard (@pytest.mark.lerobot) for upstream drift
    ### Entry points ([project.scripts])
    - so101-patch-lerobot, so101-scan-servos, so101-demo, so101-coord
    - Moved scripts/ → app/so101/ as proper package entry points
    ### Documentation
    - docs/hardware/bringup.md — full 8-step bringup guide + troubleshooting
    - docs/hardware/two-dof-pipette.md — 2-DOF varian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
    [coordinate_cmd.py, patch_lerobot.py, scan_servos.py]
2026-04-16 refactor(eln_client): replace 10 pyright ignores with single Any cast (#80)
    * refactor(eln_client): replace 10 pyright ignores with single Any cast
    elabapi_python is untyped — every attribute access required a separate
    pyright: ignore comment. Cast the imported module to Any once, so all
    downstream member access flows through Any cleanly.
    10 inline suppressions → 1.
    * test: add run_demo use-case branch tests to reach 80% coverage
    Add uc1_single, uc2, uc3 tests with --mode eval to exercise the elif
    dispatch branches in run_demo.main(). Without --mode eval, the default
    "full" short-circuits to uc4_demo_all, leaving branches uncovered.
    Co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
    [eln_client.py]
2026-04-17 ci: pin all GHA actions to full-length commit SHAs (#85)
    Pin 6 unpinned action references across 3 workflows to enable
    "Require actions to be pinned to a full-length commit SHA" repo setting.
    bump-my-version.yaml:
    - actions/checkout v4 → v6.0.0 (align with repo)
    - callowayproject/bump-my-version 0.29.0 → SHA
    - astral-sh/setup-uv v5 → v7.6.0 (align with repo)
    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
2026-04-17 Bump version: 0.1.0 → 0.2.0 (#84)
2026-04-17 fix(ci): stale template paths + direct-push to protected main (#86)
    * fix: update stale src/biolab/ paths in llms.txt template
    Template still referenced pre-restructure paths (src/biolab/, src/dashboard/).
    Updated to app/so101/ and app/dashboard/ to match current project layout.
    * fix(ci): use branch+PR instead of direct push to protected main
    Both generate-sbom and write-llms-txt workflows failed because they
    tried to git push directly to main, which is branch-protected (requires
    PR + verified signatures).
    Replace direct push with: create branch → commit → push → gh pr create.
    Also fix write-llms-txt trigger path (src/** → app/**).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
2026-04-18 refactor: rename app/ to src/ + CLI subpackage (#95)
    * refactor: rename app/ to src/ (PyPA src layout)
    Move library modules, dashboard, and hardware code from app/ to src/
    following the PyPA-recommended src layout convention.
    * refactor: add cli/ subpackage __init__.py
    * refactor: update pyproject.toml paths for src/ layout
    Update packages, entry points, ruff, pyright, pytest, and coverage
    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
    [fridge_hook.scad, gripper_tips.scad, pipette_mount.scad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]
2026-04-23 chore: align LICENSE with canonical ASF Apache-2.0 text (#112)
    * chore: align LICENSE with canonical ASF Apache-2.0 text
    Three word-level deviations from GitHub/ASF canonical:
    - §1 Contribution: "submitted to the Licensor" → "submitted to Licensor"
    - §1 Contributor: "received by the Licensor" → "received by Licensor"
    - §4(d): "excluding any notices" → "excluding those notices"
    Closes #74.
    * chore: use original Apache-2.0 text from apache.org with full APPENDIX
    Replaces LICENSE with verbatim canonical text from
    https://www.apache.org/licenses/LICENSE-2.0.txt, including the
    APPENDIX boilerplate paragraphs previously omitted. Substitu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
2026-04-23 fix: update hardware README link after app/→src/ refactor (#114)
    docs/demo-scenarios.md referenced app/hardware/README.md but the
    directory was renamed to src/hardware/ in the v0.2.0 refactor.
    Unblocks linkChecker for all PRs.
    Closes #110.
2026-04-27 ci(lint): adopt centralized markdown + link checking from qte77/.github (#123)
    Adds CI-blocking md + link lint on PR/push to main. Existing links-fail-fast.yaml (scheduled monitoring + issue creation) is kept — serves a different purpose.
2026-04-27 ci(lint): bump SHA pin and add scheduled monitor (#127)
    - lint-md-links.yml: bump uses ref to current qte77/.github main
    - lint-monitor.yml: new weekly cron + workflow_dispatch caller with notify_on_failure: true
2026-05-03 feat: wire dPette USB driver as optional pipette dependency (#61) (#117)
    Adds `pipette` optional dependency group pointing at
    Lambda-Biolab/dpette-usb-driver via [tool.uv.sources]. This unblocks
    ElectronicPipette's dpette driver resolution path — `uv sync --group
    pipette` now installs the real driver, with automatic fallback to
    stub mode when hardware is absent.
    The integration scaffold in src/so101/pipette.py::ElectronicPipette
    was already in place (imports from dpette.config and dpette.driver,
    graceful stub fallback on ImportError/connection failure) — only the
    dependency declaration was missing.
    Rationale for [tool.uv.sources] over .gitmodules: driver is an
    independent library we co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
2026-05-03 feat(cad): thicken cam arm + increase length for torque (#44) (#116)
    - CAM_LENGTH 32→40 (25% longer — better mechanical advantage on
    dPette+ ejector lever)
    - CAM_T 4→6 (50% thicker cross-section — resists flex/break under
    repeated use)
    - CAM_TIP_R 2→3 (50% wider contact surface — more forgiving
    positioning)
    Regenerates hardware/stl/dpette/dpette_cam_arm.stl and
    hardware/svg/dpette/dpette_cam_arm.svg. 323 tests pass.
    Closes #44.
    [dpette_cam_arm.stl]
2026-05-17 feat(cad): STEP export + FreeCAD round-trip fallback (#156)
    * feat(cad): export STEP alongside STL/SVG for FreeCAD round-trip
    Adds export_step in the render.py pipeline and util/export.py helper so every
    build123d part now produces a .step file under hardware/step/<subdir>/. STEP is
    the escape hatch for WYSIWYG hand-edits in FreeCAD when parametric Python is
    awkward (face drag, manual fillet, scan-trace cleanup).
    Adds make setup_freecad recipe — Flatpak on Linux (per FreeCAD wiki), Homebrew
    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
    [96well_plate_holder.step, dpette_cam_arm.step, dpette_ejector_lever.step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]
2026-05-31 docs: perception/LIDAR landscape outlook + roadmap spatial-awareness section (#172)
    * docs(docs): add perception/LIDAR landscape outlook
    Survey of depth (RealSense D405 / Orbbec / OAK-D SR), 360 deg LIDAR (Livox Mid-360, Unitree L1/L2, MANDEYE + HDMapping), and
    photogrammetry (OpenScan). Per-need capability mapping, two-track scoping (workcell vs lab-room), USD/IFC digital-twin angle. Informational;
    tracking #170 (do now) and #171 (deferred, blocked on mobile base).
    * docs(docs): add spatial-awareness section to roadmap
    Tracks (a)/(b) and capability->tool mapping under VLM + Embodied AI phase. References outlook-perception-lidar.md and issues #170
    / #171.
    ---------
    Co-authored-by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
2026-06-19 style+ci: fix ruff format drift, adopt push-based CodeQL (#167) (#193)
    * style: apply ruff format to CLI scripts and test_arms
    Pre-existing ruff format drift in 4 files broke `make validate`'s lint step (ruff format --check). No logic changes — whitespace/formatting only.
    * ci(codeql): push-based triggers + dismiss-alerts step (#167)
    Per #167: drop the pull_request trigger and the push branches:[main] filter (push now scans every branch, eliminating the merge-ref SARIF race), and add advanced-security/dismiss-alerts so inline # codeql[...] suppressions actually dismiss rather than reopen each scan. Completes the CodeQL half of #167; the De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
    [foxglove_viz.py, patch_lerobot.py, scan_servos.py]
2026-06-19 fix(deps): resolve 25/28 Dependabot alerts; fix dependabot uv ecosystem (#190)
    Drop the [tool.uv] exclude-newer cap (every patch post-dated the 2026-04-11
    pin, so no fix was reachable) and re-lock affected packages: starlette
    1.0.0->1.3.1 (+ fastapi>=0.136.1 for the 1.x line), aiohttp 3.13.5->3.14.1,
    gitpython 3.1.46->3.1.50, urllib3 2.6.3->2.7.0, lxml 6.0.3->6.1.1, idna
    3.11->3.18. Clears 25 of 28 alerts (10 of 12 high).
    Root cause of the backlog: .github/dependabot.yaml used the 'pip' ecosystem,
    which does not update uv.lock, so transitive lockfile fixes were never
    proposed. Switched to 'uv' ecosystem with grouped updates, chore(deps)/
    chore(ci) prefixes, and labels.
    Unfixed (tracked, op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
2026-06-19 fix(deps): pin lerobot>=0.4.4 to block CVE-driven downgrade (#204)
    PR #199 (torch 2.10.0->2.12.1, merged) silently downgraded lerobot 0.4.4->0.3.2 because lerobot 0.4.4 caps torch; uv satisfied the bump by rolling lerobot back. That breaks the lerobot-0.4.4-specific patch tooling (patch_lerobot.py, STS3215 mixed firmware) and isn't caught by CI (lerobot group not installed there). Same trap closed diffusers PR #198.
    Pinning lerobot[feetech]>=0.4.4 in the lerobot + train groups and re-locking restores lerobot 0.4.4 and reverts torch->2.10.0 / diffusers stays 0.35.2 (its 0.4.4-compatible versions), and prevents future CVE bumps from downgrading it. All #190 security fixes (starlette/aiohttp/u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
2026-06-19 ci: ignore lerobot-capped deps + commit SBOM directly to main (#208)
    * ci(dependabot): ignore torch/diffusers (lerobot-capped)
    Their CVE-patched versions only resolve by downgrading lerobot 0.4.4 (breaks patch_lerobot.py). The alerts are dismissed as tolerable risk and lerobot is pinned >=0.4.4; ignoring them keeps the harmful bumps out of version-update / grouped PRs.
    * ci(sbom): commit SBOM directly to main instead of per-merge PRs
    The SBOM action opened a timestamped PR on every push to main; branch protection blocks those docs-only PRs (required code checks don't run), so they piled up. Switch to create_pr: false and commit docs/SBOM str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

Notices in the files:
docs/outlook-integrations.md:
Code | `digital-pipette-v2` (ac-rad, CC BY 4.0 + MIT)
